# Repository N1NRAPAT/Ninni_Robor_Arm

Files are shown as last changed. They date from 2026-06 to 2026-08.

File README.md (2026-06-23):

# Ninni Robot Arm 

**Summer Project** · Started: 21 June 2026 · Author: Ninrapat Suttinual

An open-source 5-DOF desktop robot arm integrating **STM32 firmware**, **ROS2**, **Docker**, and **CUDA**-accelerated computer vision — built from scratch as a hands-on study of robotics, kinematics, and real-time perception.

---

##  Theory & Concepts

### Forward Kinematics (FK)
Given a set of joint angles **θ = [θ₁, θ₂, θ₃, θ₄, θ₅]**, FK computes the position and orientation of the end-effector (gripper) in 3D space using **Denavit–Hartenberg (DH) parameters**. Each joint transformation is represented as a 4×4 homogeneous transformation matrix:

```
T = Rot(z, θ) · Trans(0,0,d) · Trans(a,0,0) · Rot(x, α)
```

The final end-effector pose is the product of all joint transforms: **T_total = T₁ · T₂ · T₃ · T₄ · T₅**

### Inverse Kinematics (IK)
Given a target position **(x, y, z)** and orientation, IK solves for the joint angles required. For a 5-DOF arm this problem may be underdetermined (infinite solutions) or may require numerical solvers. Approaches explored:
- **Geometric/analytical IK** — closed-form solution for specific configurations
- **Jacobian-based numerical IK** — iterative solver via pseudo-inverse of the Jacobian matrix
- **MoveIt2 IK plugins** — leverage KDL or TRAC-IK within the ROS2 ecosystem

### ROS2 Architecture
The system uses a publish/subscribe model across nodes:
- `joint_state_publisher` → publishes current joint states
- `robot_state_publisher` → broadcasts URDF transforms (TF tree)
- `moveit2` → motion planning server
- `cv_node` → CUDA vision pipeline, publishes detected object poses
- `serial_bridge` → relays ROS2 joint commands to STM32 over USB serial

### CUDA Computer Vision
Real-time perception runs on an RTX 5080 GPU inside a Docker container. The pipeline:
1. Capture frames from Logitech USB webcam via `usb_cam` ROS2 node
2. Run object detection / pose estimation (CUDA-accelerated)
3. Publish target pose to ROS2 topic → feed into IK solver

---

##  System Architecture

```
┌─────────────────────────────────────────────┐
│              Windows PC (Host)              │
│  ┌─────────────────┐  ┌──────────────────┐  │
│  │   WSL2 Ubuntu   │  │  Docker Container│  │
│  │   22.04         │  │  CUDA 12.8       │  │
│  │                 │  │                  │  │
│  │  RViz2 (WSLg)   │  │  MoveIt2         │  │
│  │  ROS2 Humble    │◄─►  CV Pipeline     │  │
│  │  Serial Bridge  │  │  Kinematics Node │  │
│  └────────┬────────┘  └──────────────────┘  │
│           │ USB Serial (/dev/ttyACM0)        │
└───────────┼─────────────────────────────────┘
            │
   ┌────────▼──────────────┐
   │  NUCLEO-F446RE (STM32)│
   │  Servo Executor        │
   │  Half-duplex UART bus  │
   └────────┬──────────────┘
            │ TTL Bus (daisy-chain)
   ┌────────▼──────────────┐
   │  5× Feetech STS3215   │
   │  Servos (12V, 30kg·cm)│
   └───────────────────────┘
```

---

##  STM32 NUCLEO-F446RE — Pin Mapping

| Pin | Label | Connected To | Notes |
|-----|---|---|---|
| PA9 | USART1_TX | Servo Bus TX | Half-duplex TTL UART to STS3215 chain |
| PA10 | USART1_RX | Servo Bus RX | Half-duplex receive |
| PA8 | GPIO OUT | Bus Direction Pin | HIGH = TX, LOW = RX (half-duplex control) |
| CN1 USB | USB Device / ST-Link | PC via USB cable | Serial bridge to ROS2 (`/dev/ttyACM0`) |
| VIN (CN6) | 12V Power In | External 12V PSU | Powers STM32 + logic side |
| GND | Ground | Shared ground | Common with servo power rail |
| PA0 | GPIO (optional) | Status LED / Debug | Heartbeat or fault indicator |
| PB6 | USART1_TX alt | (Reserve) | Alt pin if PA9 conflicts |

> **Note:** The Feetech STS3215 uses a **single-wire half-duplex UART** bus. TX and RX share the same wire via the Waveshare Bus Servo Adapter (A). The direction-control GPIO must toggle before each read/write operation.

##  Hardware BOM

| Component | Model | Qty | Unit Price (USD) | Notes |
|---|---|-----|---|---|
| Smart Servo | Feetech STS3215 | 5 | ~$15 | 12V, 30 kg·cm, TTL half-duplex, 360° |
| Servo Bus Adapter | Waveshare Bus Servo Adapter (A) | 1 | ~$10 | USB-to-TTL bridge |
| MCU | STM32 NUCLEO-F446RE | 1 | ~$20 | 180 MHz, ST-Link onboard |
| Webcam | Logitech USB Camera | 1 | — | ROS2 `usb_cam` compatible |
| Power Supply | 12V / 8–10A switching PSU | 1 | ~$15 | Powers all servos |
| PC (GPU) | RTX 5080 host | 1 | — | CUDA 12.8 Docker, RViz2 via WSLg |

---

##  Development Roadmap

### Phase 1 — Infrastructure 
- [x] ROS2 Humble installed on PC (WSL2 Ubuntu 22.04)
- [x] CUDA 12.8 verified in Docker (RTX 5080, `sm_89`)
- [x] RViz2 running via WSLg
- [x] Architecture finalized: PC + Docker + STM32

### Phase 2 — Robot Description & Visualization 
- [ ] Write URDF for 5-DOF arm
- [ ] Launch `robot_state_publisher` + `joint_state_publisher_gui`
- [ ] Visualize full arm in RViz2 with interactive sliders
- [ ] Assign unique IDs to all 5 STS3215 servos

### Phase 3 — Firmware & Hardware Loop
- [ ] STM32 PlatformIO firmware: receive joint commands over USB serial
- [ ] Half-duplex UART driver for STS3215 bus
- [ ] Round-trip test: ROS2 → serial → STM32 → servo moves

### Phase 4 — Kinematics
- [ ] Implement FK using DH parameters
- [ ] Implement analytical IK for the 5-DOF configuration
- [ ] Validate FK/IK in simulation vs. physical arm

### Phase 5 — Computer Vision
- [ ] CUDA object detection pipeline (camera → detected pose)
- [ ] Publish target pose as ROS2 topic
- [ ] Connect vision output to IK → arm reaches detected object

### Phase 6 — MoveIt2 & Motion Planning
- [ ] MoveIt2 configuration package
- [ ] Collision-aware path planning
- [ ] Demo: pick-and-place with vision-guided grasping

---

##  Software Stack

| Layer | Tool | Purpose |
|---|---|---|
| OS | Ubuntu 22.04 (WSL2) | ROS2 native environment |
| Containerization | Docker + NVIDIA Container Toolkit | Reproducible CUDA + MoveIt2 |
| Robot Framework | ROS2 Humble | Node communication, TF, visualization |
| Visualization | RViz2 (via WSLg) | Real-time 3D arm model |
| Motion Planning | MoveIt2 | Path planning, IK, collision |
| Vision / GPU | CUDA 12.8 | Accelerated CV pipeline |
| Firmware IDE | PlatformIO + VS Code | STM32 firmware development |
| Version Control | Git / GitHub | [Ninni_Robor_Arm](https://github.com/N1NRAPAT/Ninni_Robor_Arm) |

---

##  Getting Started

```bash
# Clone the repo
git clone https://github.com/N1NRAPAT/Ninni_Robor_Arm.git
cd Ninni_Robor_Arm

# Build Docker image (from project root)
docker build -f docker/Dockerfile . -t ninni_arm

# Run with GPU support
docker run --gpus all --rm -it ninni_arm

# Launch RViz2 (WSL2 native)
source /opt/ros/humble/setup.bash
rviz2
```

---

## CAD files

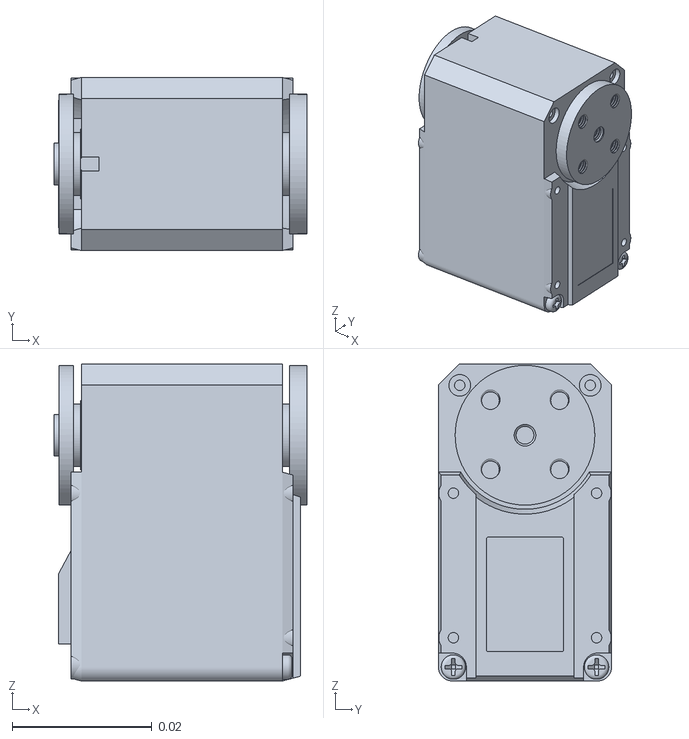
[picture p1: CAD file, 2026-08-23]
ninni_robot_arm/meshes/j3_servo__2.stl
0.0362 x 0.0248 x 0.0454

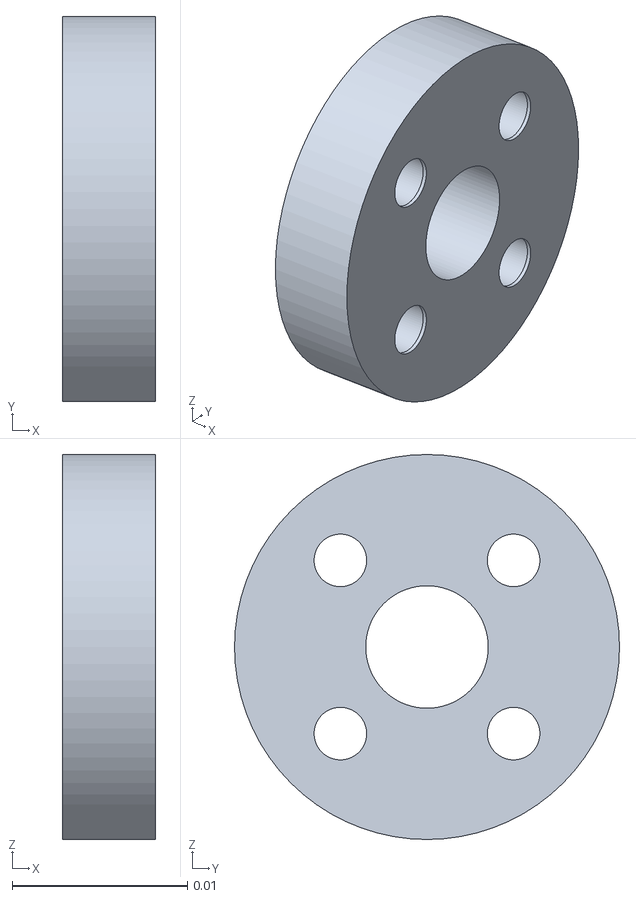
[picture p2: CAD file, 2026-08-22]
ninni_robot_arm/meshes/left_cover__3.stl
0.0053 x 0.022 x 0.022

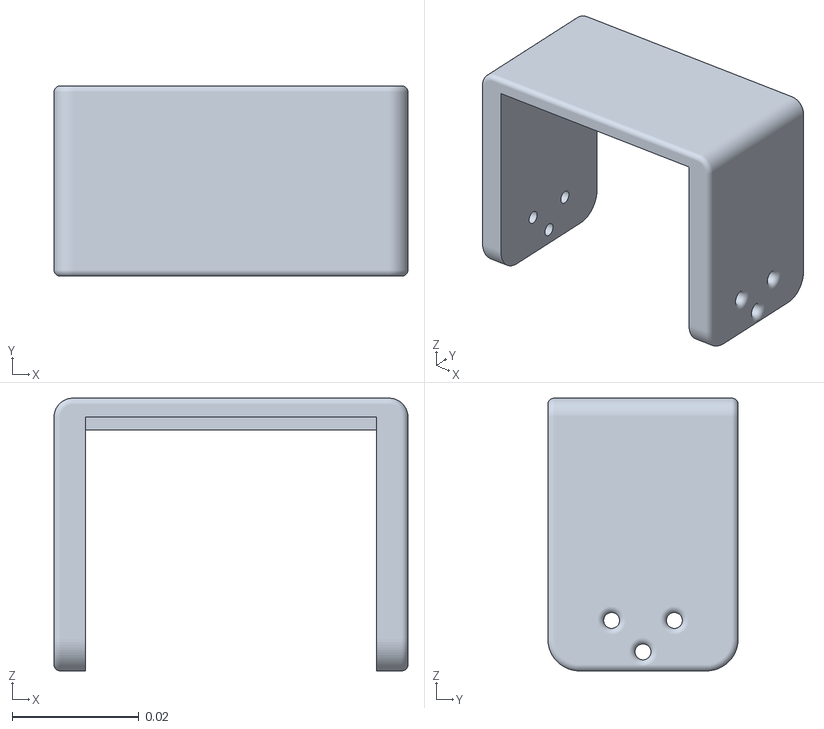
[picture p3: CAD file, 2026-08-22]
onshape_export/assets/top_arm.stl
0.0558 x 0.03 x 0.043

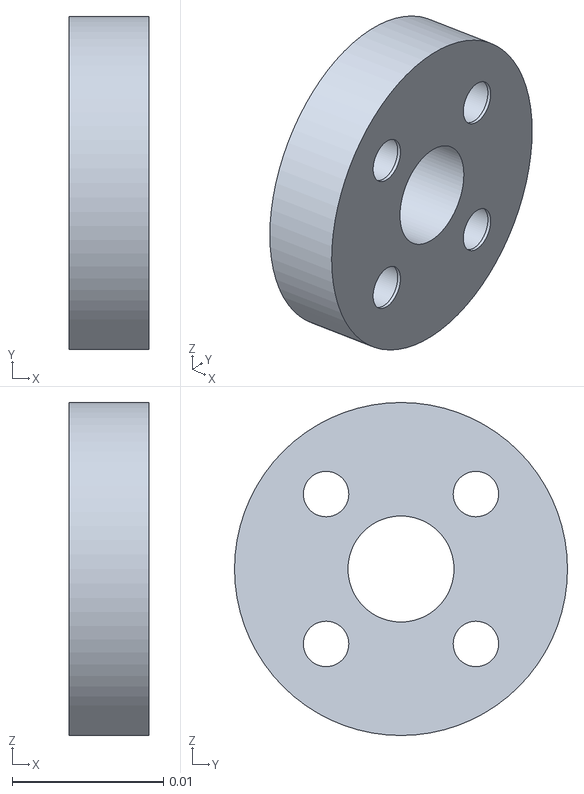
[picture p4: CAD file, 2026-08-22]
ninni_robot_arm/meshes/left_cover.stl
0.0053 x 0.022 x 0.022

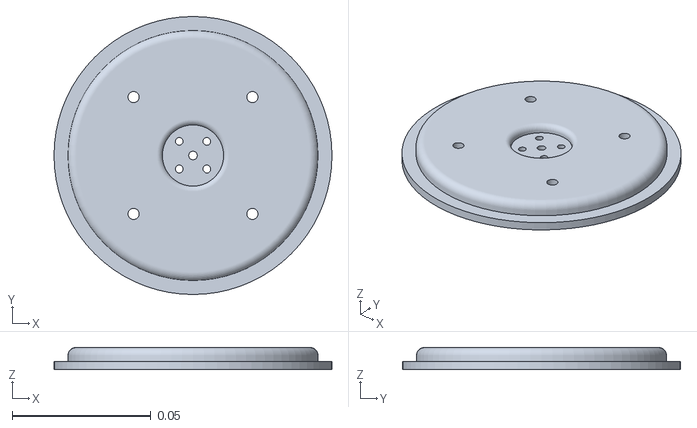
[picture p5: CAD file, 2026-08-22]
ninni_robot_arm/meshes/base_of_shoulder.stl
0.1 x 0.1 x 0.008

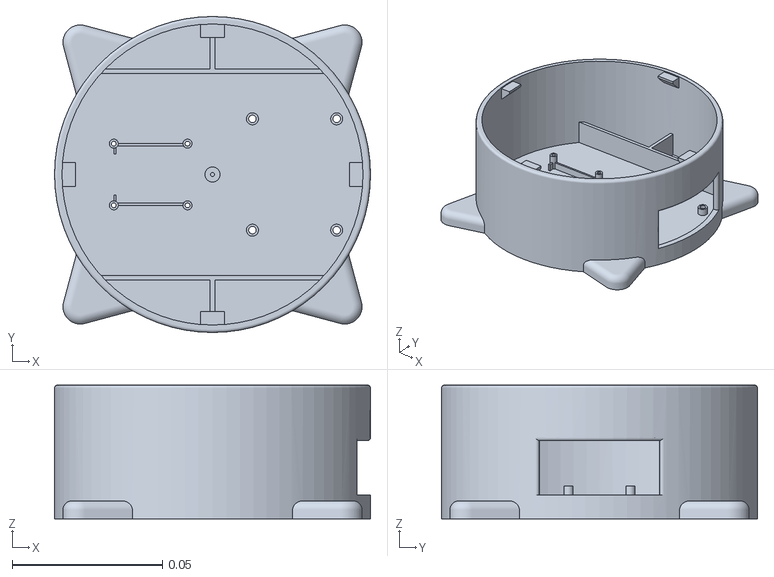
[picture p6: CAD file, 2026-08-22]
ninni_robot_arm/meshes/base_servo_board.stl
0.105 x 0.105 x 0.0445

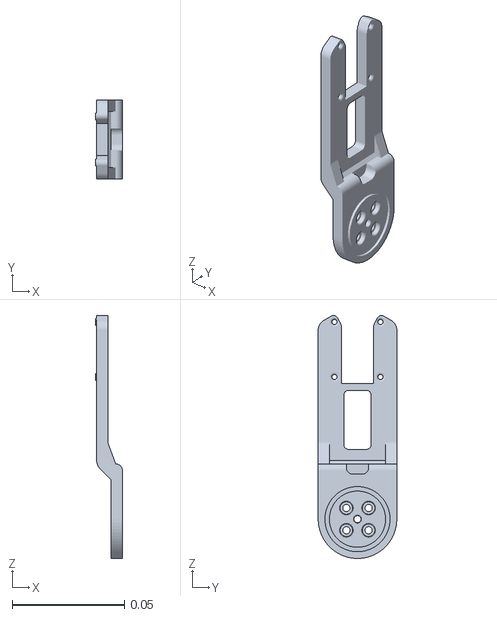
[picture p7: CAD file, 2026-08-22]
ninni_robot_arm/meshes/elbow_right.stl
0.012 x 0.035 x 0.108

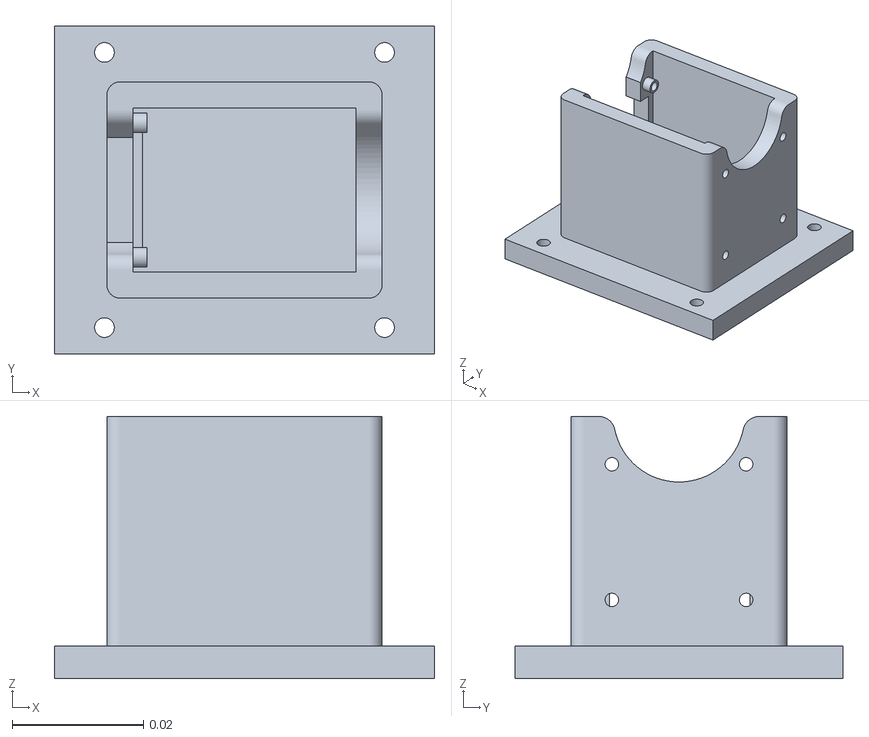
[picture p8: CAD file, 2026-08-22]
ninni_robot_arm/meshes/socker_j1.stl
0.058 x 0.05 x 0.04

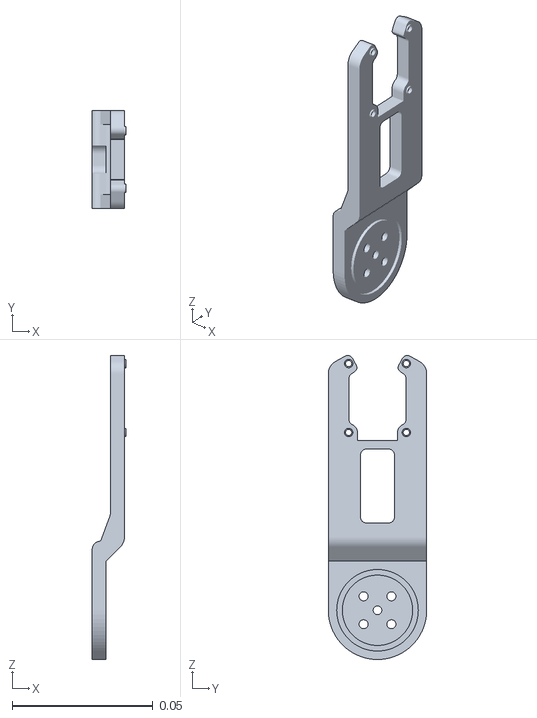
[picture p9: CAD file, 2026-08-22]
ninni_robot_arm/meshes/elbow_left.stl
0.012 x 0.035 x 0.108

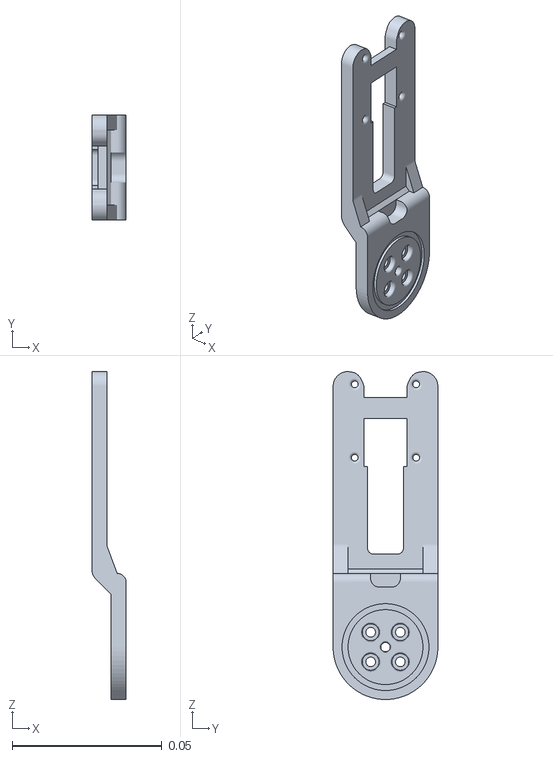
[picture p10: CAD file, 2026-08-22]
ninni_robot_arm/meshes/shoulder_right.stl
0.0115 x 0.035 x 0.109

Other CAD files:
ninni_robot_arm/meshes/servo_motor_sts3215_v10.stl
onshape_export/assets/j2_servo.stl
ninni_robot_arm/meshes/j2_servo.stl
onshape_export/assets/servo_motor_sts3215_v10.stl
ninni_robot_arm/meshes/left_cover__2.stl
ninni_robot_arm/meshes/j3_servo.stl
ninni_robot_arm/meshes/right_cover.stl
ninni_robot_arm/meshes/shoulder_left.stl

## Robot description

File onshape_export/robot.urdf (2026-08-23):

<?xml version="1.0" ?>
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
<robot name="onshape_export">
  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
  <link name="base_servo_board">
    <inertial>
      <origin xyz="-0.0133535 0.0277534 0.0174126" rpy="0 0 0"/>
      <mass value="0.129831"/>
      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
    </inertial>
    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
  </link>
  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
  <link name="base_of_shoulder">
    <inertial>
      <origin xyz="0.000212166 -0.000490641 -0.0181865" rpy="0 0 0"/>
      <mass value="0.158649"/>
      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
    </inertial>
    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
  </link>
  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
  <link name="shoulder_left">
    <inertial>
      <origin xyz="1.782e-09 0.0588026 0.0179401" rpy="0 0 0"/>
      <mass value="0.0926197"/>
      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
    </inertial>
    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
  </link>
  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
  <link name="left_cover">
    <inertial>
      <origin xyz="1.757e-09 0.0585345 0.0179499" rpy="0 0 0"/>
      <mass value="0.0917628"/>
      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
    </inertial>
    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
  </link>
  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
  <link name="left_cover_2">
    <inertial>
      <origin xyz="4.777e-09 0.0204021 0.0176066" rpy="0 0 0"/>
      <mass value="0.0268203"/>
      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
    </inertial>
    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
  </link>
  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
  <joint name="left_3_arm" type="revolute">
    <origin xyz="0 0.096 -1.91259e-05" rpy="0 0 0"/>
    <parent link="left_cover"/>
    <child link="left_cover_2"/>
    <axis xyz="0 0 1"/>
    <limit effort="10" velocity="10" lower="-2.0944" upper="2.0944"/>
  </joint>
  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
  <joint name="left_2_arm" type="revolute">
    <origin xyz="0 0.096 -1.91259e-05" rpy="0 -0 0"/>
    <parent link="shoulder_left"/>
    <child link="left_cover"/>
    <axis xyz="0 0 1"/>
    <limit effort="10" velocity="10" lower="-2.0944" upper="2.0944"/>
  </joint>
  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
  <joint name="left_1_arm" type="revolute">
    <origin xyz="0.000373 0.0169731 -0.049" rpy="-1.5708 -0 -3.14159"/>
    <parent link="base_of_shoulder"/>
    <child link="shoulder_left"/>
    <axis xyz="0 0 1"/>
    <limit effort="10" velocity="10" lower="-1.5708" upper="1.5708"/>
  </joint>
  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
  <joint name="Servor_1_to_waist" type="revolute">
    <origin xyz="-0.0133535 0.021776 0.0426284" rpy="-3.14159 0 -1.5708"/>
    <parent link="base_servo_board"/>
    <child link="base_of_shoulder"/>
    <axis xyz="0 0 1"/>
    <limit effort="10" velocity="10" lower="-3.14159" upper="3.14159"/>
  </joint>
</robot>

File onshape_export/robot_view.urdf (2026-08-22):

<?xml version="1.0" ?>
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
<robot name="onshape_export">
  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
  <link name="base_of_shoulder">
    <inertial>
      <origin xyz="0 0 0" rpy="0 0 0"/>
      <mass value="0"/>
      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
    </inertial>
    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
  </link>
  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
  <link name="base_servo_board">
    <inertial>
      <origin xyz="0 0 0" rpy="0 0 0"/>
      <mass value="0"/>
      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
    </inertial>
    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
  </link>
  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
  <joint name="Servor_1_to_waist" type="revolute">
    <origin xyz="-0.0133535 0.021776 0.0426284" rpy="0 -0 -1.5708"/>
    <parent link="base_of_shoulder"/>
    <child link="base_servo_board"/>
    <axis xyz="0 0 1"/>
    <limit effort="10" velocity="10" lower="-12.5664" upper="0"/>
  </joint>
  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
  <link name="shoulder_left">
    <inertial>
      <origin xyz="0 0 0" rpy="0 0 0"/>
      <mass value="0"/>
      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
    </inertial>
    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
  </link>
  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
  <link name="left_cover">
    <inertial>
      <origin xyz="0 0 0" rpy="0 0 0"/>
      <mass value="0"/>
      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
    </inertial>
    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
  </link>
  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
  <link name="left_cover_2">
    <inertial>
      <origin xyz="0 0 0" rpy="0 0 0"/>
      <mass value="0"/>
      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
    </inertial>
    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
  </link>
  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
  <joint name="left_3_arm" type="revolute">
    <origin xyz="0 0.096 -1.91259e-05" rpy="0 0 0"/>
    <parent link="left_cover"/>
    <child link="left_cover_2"/>
    <axis xyz="0 0 1"/>
    <limit effort="10" velocity="10" lower="-2.0944" upper="2.0944"/>
  </joint>
  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
  <joint name="left_2_arm" type="revolute">
    <origin xyz="-0 0.096 -1.91259e-05" rpy="-0 -0 -0"/>
    <parent link="shoulder_left"/>
    <child link="left_cover"/>
    <axis xyz="0 0 1"/>
    <limit effort="10" velocity="10" lower="-2.26893" upper="2.26893"/>
  </joint>
  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
  <joint name="left_1_arm" type="revolute">
    <origin xyz="-0.0303266 0.021403 0.0916284" rpy="1.5708 0 1.5708"/>
    <parent link="base_of_shoulder"/>
    <child link="shoulder_left"/>
    <axis xyz="0 0 1"/>
    <limit effort="10" velocity="10" lower="-1.65806" upper="1.65806"/>
  </joint>
</robot>

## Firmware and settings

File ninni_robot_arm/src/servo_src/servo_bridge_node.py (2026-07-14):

#!/usr/bin/env python3


import glob
import rclpy
from rclpy.node import Node
from sensor_msgs.msg import JointState
from scservo_sdk import sms_sts, PortHandler
import math


"""AUTO-DETECT SERVO PORT

This fuction is set to auto-detect the serial port that the servo is connected to. 
It scans through /dev/ttyACM* and /dev/ttyUSB* and pings a range of IDs on each to see if
any servo responds. If a responsive servo is found, it returns the corresponding port.
If no responsive servo is found on any port/ID combination, it returns None.

"""

def find_servo_port(baudrate, ping_ids=range(1, 6), logger=None):
    """Scan /dev/ttyACM* and /dev/ttyUSB*, return first port where ANY id in ping_ids responds."""
    candidates = sorted(glob.glob('/dev/ttyACM*') + glob.glob('/dev/ttyUSB*'))
    if logger:
        logger.info(f'Auto-detecting servo port, candidates: {candidates}, checking IDs: {list(ping_ids)}')

    for port in candidates:
        ph = PortHandler(port)
        try:
            if not ph.openPort():
                continue
            if not ph.setBaudRate(baudrate):
                ph.closePort()
                continue
            servo = sms_sts(ph)
            found_id = None
            for pid in ping_ids:
                _, result, _ = servo.ping(pid)
                if result == 0:
                    found_id = pid
                    break
            ph.closePort()
            if found_id is not None:
                if logger:
                    logger.info(f'  Found responsive servo (ID {found_id}) on {port}')
                return port
        except Exception:
            try:
                ph.closePort()
            except Exception:
                pass
            continue

    return None


class ServoBridgeNode(Node):
    def __init__(self):
        super().__init__('servo_bridge_node')

        self.declare_parameter('serial_port', 'auto') 
        self.declare_parameter('baudrate', 1000000)
        self.declare_parameter('move_speed', 2000)
        self.declare_parameter('move_acc', 100)
        self.declare_parameter('telemetry_interval', 0.5)  # seconds between telemetry reads

        requested_port = self.get_parameter('serial_port').value
        baudrate = self.get_parameter('baudrate').value

        if requested_port == 'auto':
            serial_port = find_servo_port(baudrate, ping_ids=range(1, 6), logger=self.get_logger())
            if serial_port is None:
                self.get_logger().error(
                    'Auto-detect found no responsive servo (checked IDs 1-5) on any /dev/ttyACM*/ttyUSB* port. '
                    'Check usbipd attach + 12V power, or pass serial_port explicitly.'
                    'Check wire connections and power supply to the servo. Ensure that the servo is powered and connected properly.'
                )
                raise RuntimeError('No servo port found') 
        else:
            serial_port = requested_port

        self.joint_to_servo = {
            'joint1': 1,
            'joint2': 2,
            'joint3': 3,
            'joint4': 4,
            'joint5': 5,
        }

        self.joint_config = {
            'joint1': {'offset_rad': math.pi, 'direction': 1, 'min_tick': 0, 'max_tick': 4095},
            'joint2': {'offset_rad': math.pi, 'direction': 1, 'min_tick': 0, 'max_tick': 4095},
            'joint3': {'offset_rad': math.pi, 'direction': 1, 'min_tick': 0, 'max_tick': 4095},
            'joint4': {'offset_rad': math.pi, 'direction': 1, 'min_tick': 0, 'max_tick': 4095},
            'joint5': {'offset_rad': math.pi, 'direction': 1, 'min_tick': 0, 'max_tick': 4095},
        }

        self.port_handler = PortHandler(serial_port)
        self.servo = sms_sts(self.port_handler)

        if not self.port_handler.openPort():
            self.get_logger().error(f'Failed to open serial port: {serial_port}')
            raise RuntimeError(f'Cannot open {serial_port}')

        if not self.port_handler.setBaudRate(baudrate):
            self.get_logger().error(f'Failed to set baud rate: {baudrate}')
            raise RuntimeError(f'Cannot set baudrate {baudrate}')

        self.get_logger().info(f'Servo bus opened on {serial_port} @ {baudrate}')

        for joint_name, servo_id in self.joint_to_servo.items():
            _, result, _ = self.servo.ping(servo_id)
            if result == 0:
                self.get_logger().info(f'  OK {joint_name} -> servo ID {servo_id}')
            else:
                self.get_logger().warn(f'  MISSING {joint_name} -> servo ID {servo_id}')

        self.subscription = self.create_subscription(
            JointState,
            '/joint_states',
            self.joint_states_callback,
            10
        )

        # Telemetry publisher: publishes voltage/current for all servos
        # Using JointState: name=joint names, position=voltage(V), velocity=current(mA)
        self.telemetry_pub = self.create_publisher(JointState, '/servo_telemetry', 10)
        telemetry_interval = self.get_parameter('telemetry_interval').value
        self.telemetry_timer = self.create_timer(telemetry_interval, self.telemetry_callback)

        self.get_logger().info('Servo bridge ready - listening on /joint_states')
        self.get_logger().info(f'Telemetry publishing to /servo_telemetry every {telemetry_interval}s')

    def rad_to_tick(self, angle_rad, joint_name):
        """ Converts radians to servo ticks.
        Uses the joint configuration to apply offset and direction, then scales to the servo's tick range (0-4095).
        """
        config = self.joint_config.get(joint_name, {})
        offset = config.get('offset_rad', math.pi)
        direction = config.get('direction', 1)
        min_tick = config.get('min_tick', 0)
        max_tick = config.get('max_tick', 4095)

        adjusted = direction * angle_rad + offset
        tick = int((adjusted / (2.0 * math.pi)) * 4096)
        tick = max(min_tick, min(max_tick, tick))
        return tick

    def telemetry_callback(self):
        """Read voltage and current from each servo and publish."""
        msg = JointState()
        msg.header.stamp = self.get_clock().now().to_msg()
        names = []
        voltages = []
        currents = []

        for joint_name, servo_id in self.joint_to_servo.items():
            names.append(joint_name)

            # Voltage: register 62, 1 byte, value * 0.1 = volts
            v_raw, comm_v, _ = self.servo.read1ByteTxRx(servo_id, 62)
            volts = v_raw * 0.1 if comm_v == 0 else 0.0

            # Current: register 69, 2 bytes, value in mA
            c_raw, comm_c, _ = self.servo.read2ByteTxRx(servo_id, 69)
            milliamps = float(c_raw) if comm_c == 0 else 0.0

            voltages.append(volts)
            currents.append(milliamps)

        msg.name = names
        msg.position = voltages    # voltage in V
        msg.velocity = currents    # current in mA
        self.telemetry_pub.publish(msg)

    def joint_states_callback(self, msg):
        move_speed = int(self.get_parameter('move_speed').value)
        move_acc = int(self.get_parameter('move_acc').value)
        move_acc = max(0, min(255, move_acc))

        for i, joint_name in enumerate(msg.name):
            if joint_name not in self.joint_to_servo:
                continue
            if i >= len(msg.position):
                continue

            angle_rad = msg.position[i]
            servo_id = self.joint_to_servo[joint_name]
            tick = self.rad_to_tick(angle_rad, joint_name)

            self.get_logger().info(
                f'DEBUG servo_id={servo_id} tick={tick} '
                f'move_speed={move_speed} move_acc={move_acc}'
            )

            self.servo.WritePosEx(servo_id, tick, move_speed, move_acc)
            self.get_logger().debug(
                f'{joint_name} (ID {servo_id}): {angle_rad:.3f} rad -> tick {tick}'
            )

    def destroy_node(self):
        self.get_logger().info('Shutting down - closing serial port')
        self.port_handler.closePort()
        super().destroy_node()


def main(args=None):
    rclpy.init(args=args)
    node = ServoBridgeNode()
    try:
        rclpy.spin(node)
    except KeyboardInterrupt:
        pass
    finally:
        node.destroy_node()
        rclpy.shutdown()


if __name__ == '__main__':
    main()

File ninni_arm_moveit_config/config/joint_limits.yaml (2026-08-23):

# joint_limits.yaml allows the dynamics properties specified in the URDF to be overwritten or augmented as needed

# For beginners, we downscale velocity and acceleration limits.
# You can always specify higher scaling factors (<= 1.0) in your motion requests.  # Increase the values below to 1.0 to always move at maximum speed.
default_velocity_scaling_factor: 0.1
default_acceleration_scaling_factor: 0.1

# Specific joint properties can be changed with the keys [max_position, min_position, max_velocity, max_acceleration]
# Joint limits can be turned off with [has_velocity_limits, has_acceleration_limits]
joint_limits:
  Servor_1_to_waist:
    has_velocity_limits: true
    max_velocity: 10.0
    has_acceleration_limits: false
    max_acceleration: 0.0
  left_1_arm:
    has_velocity_limits: true
    max_velocity: 10.0
    has_acceleration_limits: false
    max_acceleration: 0.0
  left_2_arm:
    has_velocity_limits: true
    max_velocity: 10.0
    has_acceleration_limits: false
    max_acceleration: 0.0
  left_3_arm:
    has_velocity_limits: true
    max_velocity: 10.0
    has_acceleration_limits: false
    max_acceleration: 0.0

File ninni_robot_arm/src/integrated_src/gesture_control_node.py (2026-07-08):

#!/usr/bin/env python3
"""
gesture_control_node.py
Subscribes to /detected_class (std_msgs/String) from yolo_detect_node.
Drives all 3 servos in continuous wheel (velocity) mode:
  - "person" detected  -> spin clockwise
  - "bottle" detected  -> spin counter-clockwise
  - nothing detected   -> stop
Type 'q' + Enter in this terminal to stop all servos, restore position
mode, and exit cleanly.

Auto-detects the correct /dev/ttyACM* port by trying each candidate and
pinging servo ID 1 - no more manually figuring out ACM0 vs ACM1 each session.
Set serial_port param to a specific path (e.g. /dev/ttyACM1) to skip auto-detect.

NOTE: wheel-mode register addresses below follow the standard Waveshare
ST3215 control table (MODE=33, TORQUE_ENABLE=40, ACC=41, GOAL_SPEED=46-47,
direction = sign+magnitude with bit15 as the direction flag). Test at low
spin_speed first - if direction is flipped or nothing moves, this is the
first place to check against your SDK's actual register map.
"""

import glob
import rclpy
from rclpy.node import Node
from std_msgs.msg import String
from scservo_sdk import sms_sts, PortHandler
import threading
import sys

ADDR_TORQUE_ENABLE = 40
ADDR_ACC = 41
ADDR_MODE = 33
ADDR_GOAL_SPEED = 46

WHEEL_MODE = 1
POSITION_MODE = 0
DIRECTION_BIT = 0x8000


# Reuse code from servo_bridge_node.py for auto-detecting the servo port
def find_servo_port(baudrate, ping_id=1, logger=None):
    """Scan /dev/ttyACM* and /dev/ttyUSB*, return first port that responds to a ping."""
    candidates = sorted(glob.glob('/dev/ttyACM*') + glob.glob('/dev/ttyUSB*')) # sort for consistent order
    if logger:
        logger.info(f'Auto-detecting servo port, candidates: {candidates}')

    for port in candidates:
        ph = PortHandler(port)
        try:
            if not ph.openPort():
                continue
            if not ph.setBaudRate(baudrate):
                ph.closePort()
                continue
        # If the port cannot be opened or the baud rate cannot be set, skip to the next candidate.
            servo = sms_sts(ph)
            _, result, _ = servo.ping(ping_id)
            ph.closePort()
            if result == 0: # mean the servo responded successfully
                if logger:
                    logger.info(f'  Found responsive servo on {port}')
                return port
        except Exception: # fail safely and continue to the next candidate
            try:
                ph.closePort()
            except Exception:
                pass
            continue

    return None


class GestureControlNode(Node):
    def __init__(self):
        super().__init__('gesture_control_node')

        self.declare_parameter('serial_port', 'auto')
        self.declare_parameter('baudrate', 1000000)
        self.declare_parameter('spin_speed', 500)
        self.declare_parameter('spin_acc', 50)

        requested_port = self.get_parameter('serial_port').value
        baudrate = self.get_parameter('baudrate').value
        self.spin_speed = int(self.get_parameter('spin_speed').value)
        self.spin_acc = max(0, min(255, int(self.get_parameter('spin_acc').value)))

        if requested_port == 'auto':
            serial_port = find_servo_port(baudrate, ping_id=1, logger=self.get_logger())
            if serial_port is None:
                self.get_logger().error(
                    'Auto-detect found no responsive servo on any /dev/ttyACM*/ttyUSB* port. '
                    'Check usbipd attach + 12V power, or pass serial_port explicitly.'
                )
                raise RuntimeError('No servo port found')
        else:
            serial_port = requested_port

        self.servo_ids = [1, 2, 3]

        self.port_handler = PortHandler(serial_port)
        self.servo = sms_sts(self.port_handler)

        if not self.port_handler.openPort():
            self.get_logger().error(f'Failed to open serial port: {serial_port}')
            raise RuntimeError(f'Cannot open {serial_port}')
        if not self.port_handler.setBaudRate(baudrate):
            self.get_logger().error(f'Failed to set baud rate: {baudrate}')
            raise RuntimeError(f'Cannot set baudrate {baudrate}')

        self.get_logger().info(f'Servo bus opened on {serial_port} @ {baudrate}')

        self._enter_wheel_mode()
        self.current_state = None

        self.subscription = self.create_subscription(
            String, '/detected_class', self.class_callback, 10)

        self.last_msg_time = self.get_clock().now()
        self.watchdog_timer = self.create_timer(0.5, self._watchdog_check)

        self.stop_flag = threading.Event()
        self._key_thread = threading.Thread(target=self._keyboard_listener, daemon=True)
        self._key_thread.start()

        self.get_logger().info(
            "Gesture control ready. person=CW, bottle=CCW. Type 'q' + Enter to stop."
        )

    def _enter_wheel_mode(self):
        for sid in self.servo_ids:
            self.servo.write1ByteTxRx(sid, ADDR_TORQUE_ENABLE, 0)
            self.servo.write1ByteTxRx(sid, ADDR_MODE, WHEEL_MODE)
            self.servo.write1ByteTxRx(sid, ADDR_ACC, self.spin_acc)
            self.servo.write1ByteTxRx(sid, ADDR_TORQUE_ENABLE, 1)
        self.get_logger().info('Servos switched to wheel mode')

    def _exit_wheel_mode(self):
        for sid in self.servo_ids:
            self._write_wheel_speed(sid, 0)
            self.servo.write1ByteTxRx(sid, ADDR_TORQUE_ENABLE, 0)
            self.servo.write1ByteTxRx(sid, ADDR_MODE, POSITION_MODE)
        self.get_logger().info('Servos returned to position mode')

    def _write_wheel_speed(self, servo_id, speed_signed):
        magnitude = min(abs(int(speed_signed)), 3400)
        raw = magnitude | DIRECTION_BIT if speed_signed < 0 else magnitude
        self.servo.write2ByteTxRx(servo_id, ADDR_GOAL_SPEED, raw)

    def _set_all(self, speed_signed):
        for sid in self.servo_ids:
            self._write_wheel_speed(sid, speed_signed)

    def class_callback(self, msg):
        self.last_msg_time = self.get_clock().now()
        label = msg.data.strip().lower()

        if label == 'person' and self.current_state != 'cw':
            self.get_logger().info('Person detected -> spinning CW')
            self._set_all(self.spin_speed)
            self.current_state = 'cw'
        elif label == 'bottle' and self.current_state != 'ccw':
            self.get_logger().info('Bottle detected -> spinning CCW')
            self._set_all(-self.spin_speed)
            self.current_state = 'ccw'
        elif label not in ('person', 'bottle') and self.current_state != 'stop':
            self._set_all(0)
            self.current_state = 'stop'

    def _watchdog_check(self):
        elapsed = (self.get_clock().now() - self.last_msg_time).nanoseconds / 1e9
        if elapsed > 1.0 and self.current_state != 'stop':
            self.get_logger().info('No recent detections -> stopping')
            self._set_all(0)
            self.current_state = 'stop'
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

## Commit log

2026-06-21 #1 : set up urdf and rviz
    [ninni_robot_arm.urdf]
2026-06-22 Initialize README with project overview
    Added project description and details for Ninni Robot Arm.
2026-06-23 few changes
    [ninni_robot_arm.urdf]
2026-06-23 add arm_rotator node, CMakeLists, package.xml
    [ninni_robot_arm.urdf]
2026-06-23 remove build/install/log from tracking, add .gitignore
    [ninni_robot_arm.urdf]
2026-06-28 #4 : STM32 snapshot on logicam
2026-07-08 SERVO link up
2026-07-08 Test and integrated : cam , yolo and servo as in one ROS2 pipeline so I control movement while detected either human or non human such like when human appear in front of the camera then servo will tu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
2026-07-14 Process #1 : Add # 3 ; Initialize servo id 4 and 5 to servo board at the begining bus route. Key takeaway is one of those servo are different series which is ST3235 high torgue 360 - 4096 degree 30 N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
2026-07-14 Progress #1 : Add #4 ; Adding sub-plot of each voltage and current read of value in real time to matplotib as output monitoring system
2026-08-22 ADD : Urdf file from onshape to robot (Rviz) directory
    [base_of_shoulder.stl, base_servo_board.stl, elbow_left.stl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]
2026-08-23 ADD : config and moveit
    [base_of_shoulder.stl, base_servo_board.stl, elbow_left.stl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]
2026-08-23 ADD : adding animation plan by code another python file top re order of sequence of chain and joint that I set up eariler in moveit assistant.
    [j2_servo.stl, j3_servo__2.stl, joint_limits.yaml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]
2026-08-27 ADD: adding forward kinematic program to Servo_src as pose_sequence_node.py. So this program does one things which is user input of angle of DOF then convert back to rad to use it inside calculation 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
2026-08-27 ADD : Inverse kinematic program to send target to RVIZ moveit
